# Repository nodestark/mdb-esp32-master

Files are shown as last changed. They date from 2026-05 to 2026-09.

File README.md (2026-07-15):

<div align="center">





# VMflow — MDB ESP32 Controller/Target Bridge

**A dual-port MDB bridge on the ESP32-S3, sitting between a vending machine's VMC and its peripherals.**
</div>

---

This project implements an **MDB bridge** between a vending machine's real VMC and its peripherals over the [Multi-Drop Bus](https://en.wikipedia.org/wiki/Multidrop_bus) protocol. The board exposes **two independent MDB ports**:

- **Controller port** — the board is the master: it drives the physical peripherals (coin changer `0x08` and bill validator `0x30`).
- **Target port** — the board is a slave: it emulates cashless (`0x10`), coin changer (`0x08`), and bill validator (`0x30`) toward the vending machine's real VMC.

The firmware bridges the two ports: coin/bill events detected on the controller port are relayed as MDB events on the target port (and enable/dispense/escrow commands the other way). Crucially, the target port **mirrors each physical peripheral's identity** to the VMC — its currency/country code, scale factor and decimal places — so the machine accepts them (a mismatched or unknown currency makes the VMC reject the device, e.g. `NOTE INCOMPAT`).

The cashless device (`0x10`) is **self-contained**: no physical cashless is bridged. Credit is granted out-of-band by the **VMflow payment engine** (BLE phone app) or the signed `credit` MQTT RPC, and each vend is approved locally against the session's available funds. Credit is bound to a single session — granted at Begin Session and destroyed at Session End/Reset — so no balance carries over or approves an out-of-session vend.

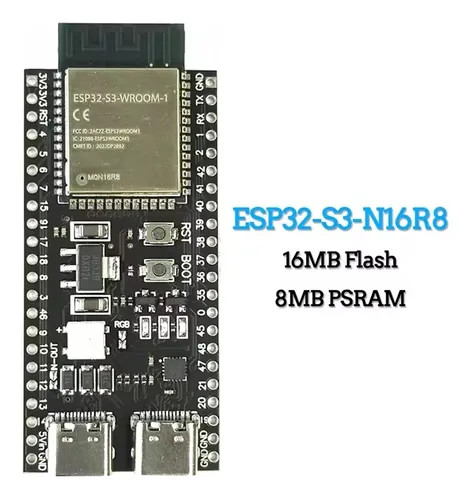
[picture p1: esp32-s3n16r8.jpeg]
ESP32-S3 N16R8


# Features
- **MDB controller↔target bridge**: bus poll loop, ACK/NAK/RET handling, 9-bit address/mode framing, on both an independent hardware-UART master port and a bit-banged slave port
- **Coin changer** (`0x08`) and **bill validator** (`0x30`) bridged as repeaters — the target port mirrors the real device's currency/country code, scale factor, decimal places, and tube/stacker counts, and forwards type-enable/dispense/escrow commands back to the physical device
- **Cashless** (`0x10`) **self-contained** on the target port — no physical cashless is bridged; credit is granted out-of-band and each vend is decided locally:
  - the **VMflow payment engine** — BLE (NimBLE) phone-app vend/session channel, HMAC-signed
  - the signed `credit` MQTT RPC command
  - credit is single-session (granted at Begin Session, destroyed at Session End/Reset); a vend is approved iff the item price fits the available funds
- **WiFi + MQTT** uplink (`mqtt.vmflow.xyz`) with signed remote-RPC commands (`info`, `safe`, `credit`, `oos`, `echo`, `restart`, `ota`) and telemetry (`vend_ok`, `vend_fail`, `sale`, `paxcounter`)
- **`info` RPC endpoint** reports firmware version, uptime and heap (plus a coin-vault snapshot)
- **`safe` RPC endpoint** reports cash currently in the machine: the **coin vault** (live tube count × per-coin credit — accurate) and the **bill vault** (value of bills stacked since boot; best-effort, since MDB never reports a bill's denomination once stacked), plus the raw bill stacker count
- **BLE passive-scan foot-traffic counter** ("paxcounter") — periodic scan classifying nearby phones by manufacturer ID/appearance, reported hourly
- **OTA** over HTTPS (`esp_https_ota`), triggered by the signed `ota` RPC command, pulling a release binary from this repo
- **WS2812 status LED** indicating provisioning/MQTT state
- Configurable via `idf.py menuconfig` → **VMflow** → MDB Cashless Device (currency/country code, scale factor, decimal places) — used as the fallback identity for any peripheral not (yet) online on the controller port
- Bare-metal **KiCad** hardware: MDB sockets + bridges, designed for low-cost production and customization
- Part of the open **VMflow** platform — pairs with the [📊 Web Dashboard](https://vmflow.xyz/dashboard) for telemetry, sales, inventory, and AI-powered diagnostics

# Hardware

The companion board (KiCad project [`kicad/`](kicad)) carries the ESP32-S3 module and the MDB interface bridge (TX/RX opto-isolation and the 9-bit UART path) plus the peripheral socket. Shared on PCBWay:

👉 **[MDB ESP32 Bridge Device — PCBWay](https://www.pcbway.com/project/shareproject/MDB_ESP32_Bridge_Device_ca013cf8.html)**

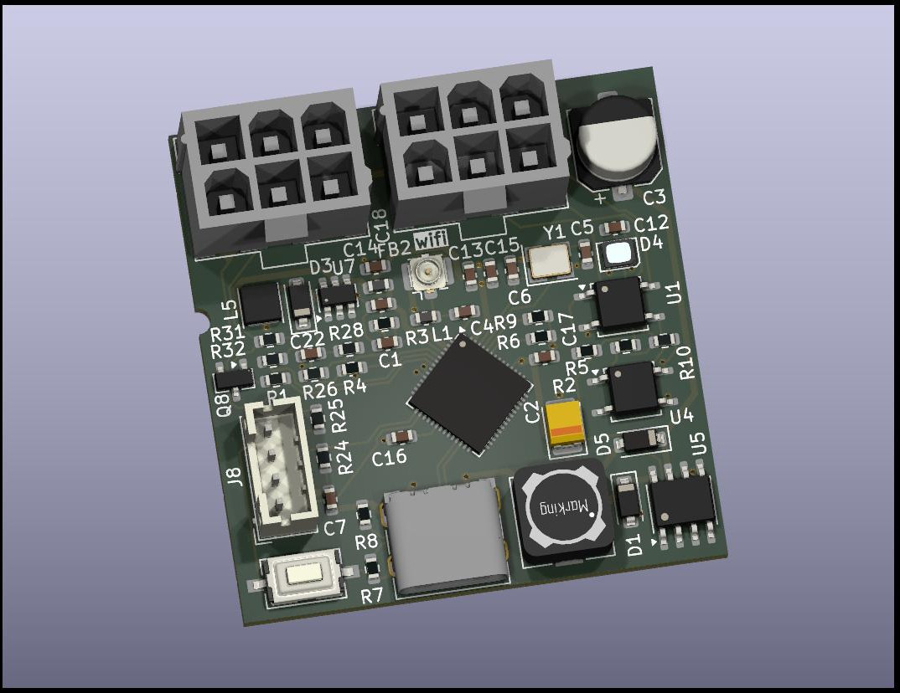
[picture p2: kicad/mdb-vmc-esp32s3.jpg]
MDB VMC ESP32-S3 PCB


PCBWay (https://www.pcbway.com/project/member/?bmbno=1B3B95CB-4E28-4D)

### MDB ports & pinout (default)

Two MDB ports — name reflects the board's role on each:

| Port | RX  | TX  | Board role | Connects to |
|---|-----|-----|---|---|
| **Controller**  | IO1 | IO2 | master (VMC) | peripherals: coin changer, bill validator |
| **Target** | IO4 | IO5 | slave (peripheral)  | the vending machine's VMC/master |

Both ports are driven at once by this firmware: peripherals plug into the **controller port**, the vending machine's real VMC plugs into the **target port**, and the firmware bridges the two.

Other pins:

| Signal | GPIO | Note |
|---|---|---|
| MDB state LED | 48 | WS2812 status LED |
| I2C SDA | 10 | reserved, not used by this firmware yet |
| I2C SCL | 11 | reserved, not used by this firmware yet |

MDB UART: 9600 baud, 9 data bits (8 data + 1 mode), even parity emulated for the 9th bit, 1 stop bit.

MDB PCB connection diagram

# Getting Started

Build with **ESP-IDF v5.x**:

```bash
# Clone the repository
git clone https://github.com/nodestark/mdb-esp32-master
cd mdb-esp32-master

idf.py menuconfig   # VMflow -> MDB Cashless Device: currency/country code, scale, decimal
idf.py build flash monitor
```

Wire the peripherals (coin changer, bill validator) to the **controller port**, and the vending machine's real VMC to the **target port**. Both sides start polling automatically — reset → setup → enable → poll. Provision WiFi/subdomain/passkey and use the cashless session from the VMflow phone app over BLE, or grant credit remotely via the signed `credit` MQTT RPC command.

# How to Contribute
- Contributions are welcome! Open issues, send pull requests, or propose new features
- Before submitting a pull request, make sure the code complies with the style and quality guidelines defined in the project
- Help improve documentation by adding usage examples, wiring notes, and peripheral compatibility reports

## License

This project is licensed under the MIT License - see the [LICENSE](LICENSE) file for details.

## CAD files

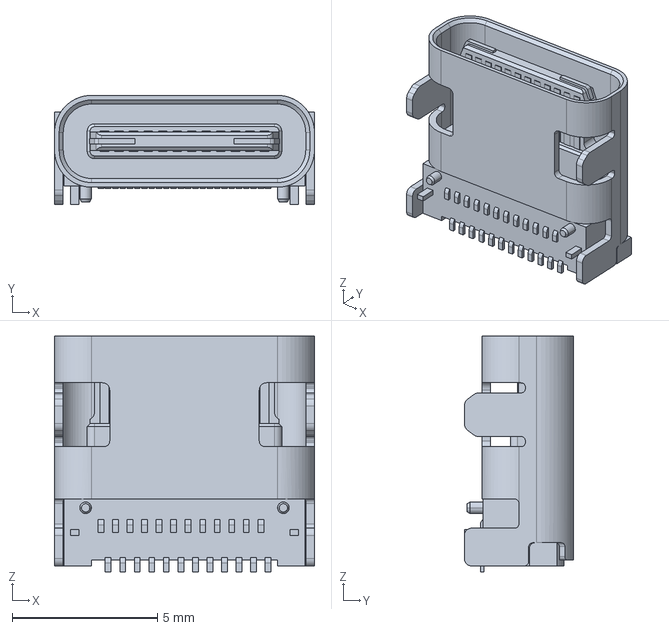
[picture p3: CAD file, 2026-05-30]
kicad/mdb-bridge-esp32s3/3d-models/USB-C_Receptacle_G-Switch-GT-USB-7010ASV.stp
8.94 x 3.76 x 8.10 mm

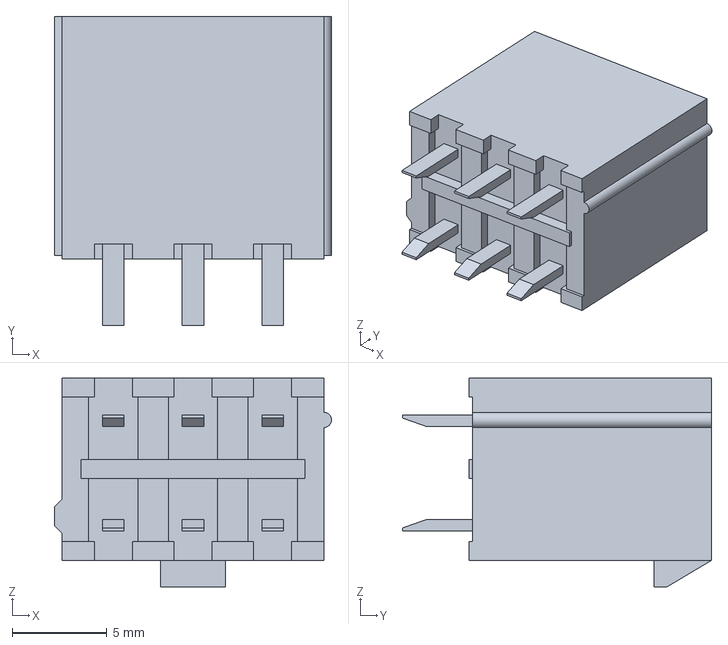
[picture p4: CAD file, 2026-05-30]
kicad/mdb-bridge-esp32s3/3d-models/Connector_Molex-MiniJr-39-28-1063_2x03.stp
14.6 x 16.3 x 11.0 mm

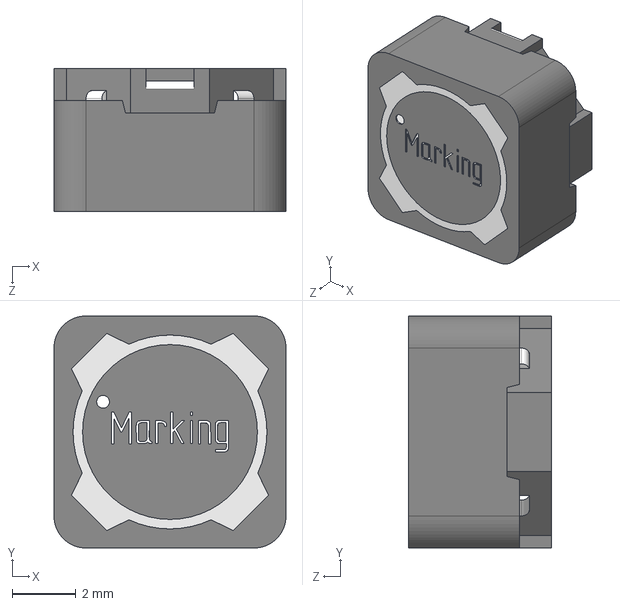
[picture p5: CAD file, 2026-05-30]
kicad/mdb-bridge-esp32s3/3d-models/Inductor_WE-7447789156_100uH.stp
7.30 x 7.30 x 4.50 mm

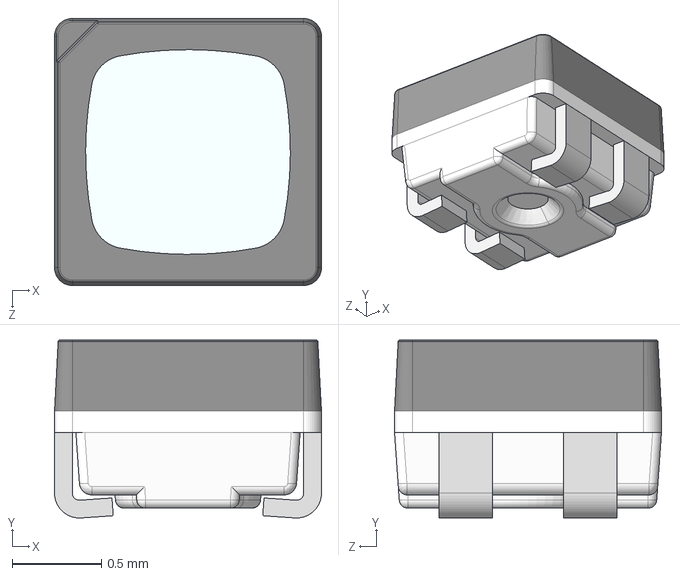
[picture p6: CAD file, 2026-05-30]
kicad/mdb-bridge-esp32s3/3d-models/LED_WS2812B-2020_XL-2121RGBC.stp
1.50 x 1 x 1.50 mm

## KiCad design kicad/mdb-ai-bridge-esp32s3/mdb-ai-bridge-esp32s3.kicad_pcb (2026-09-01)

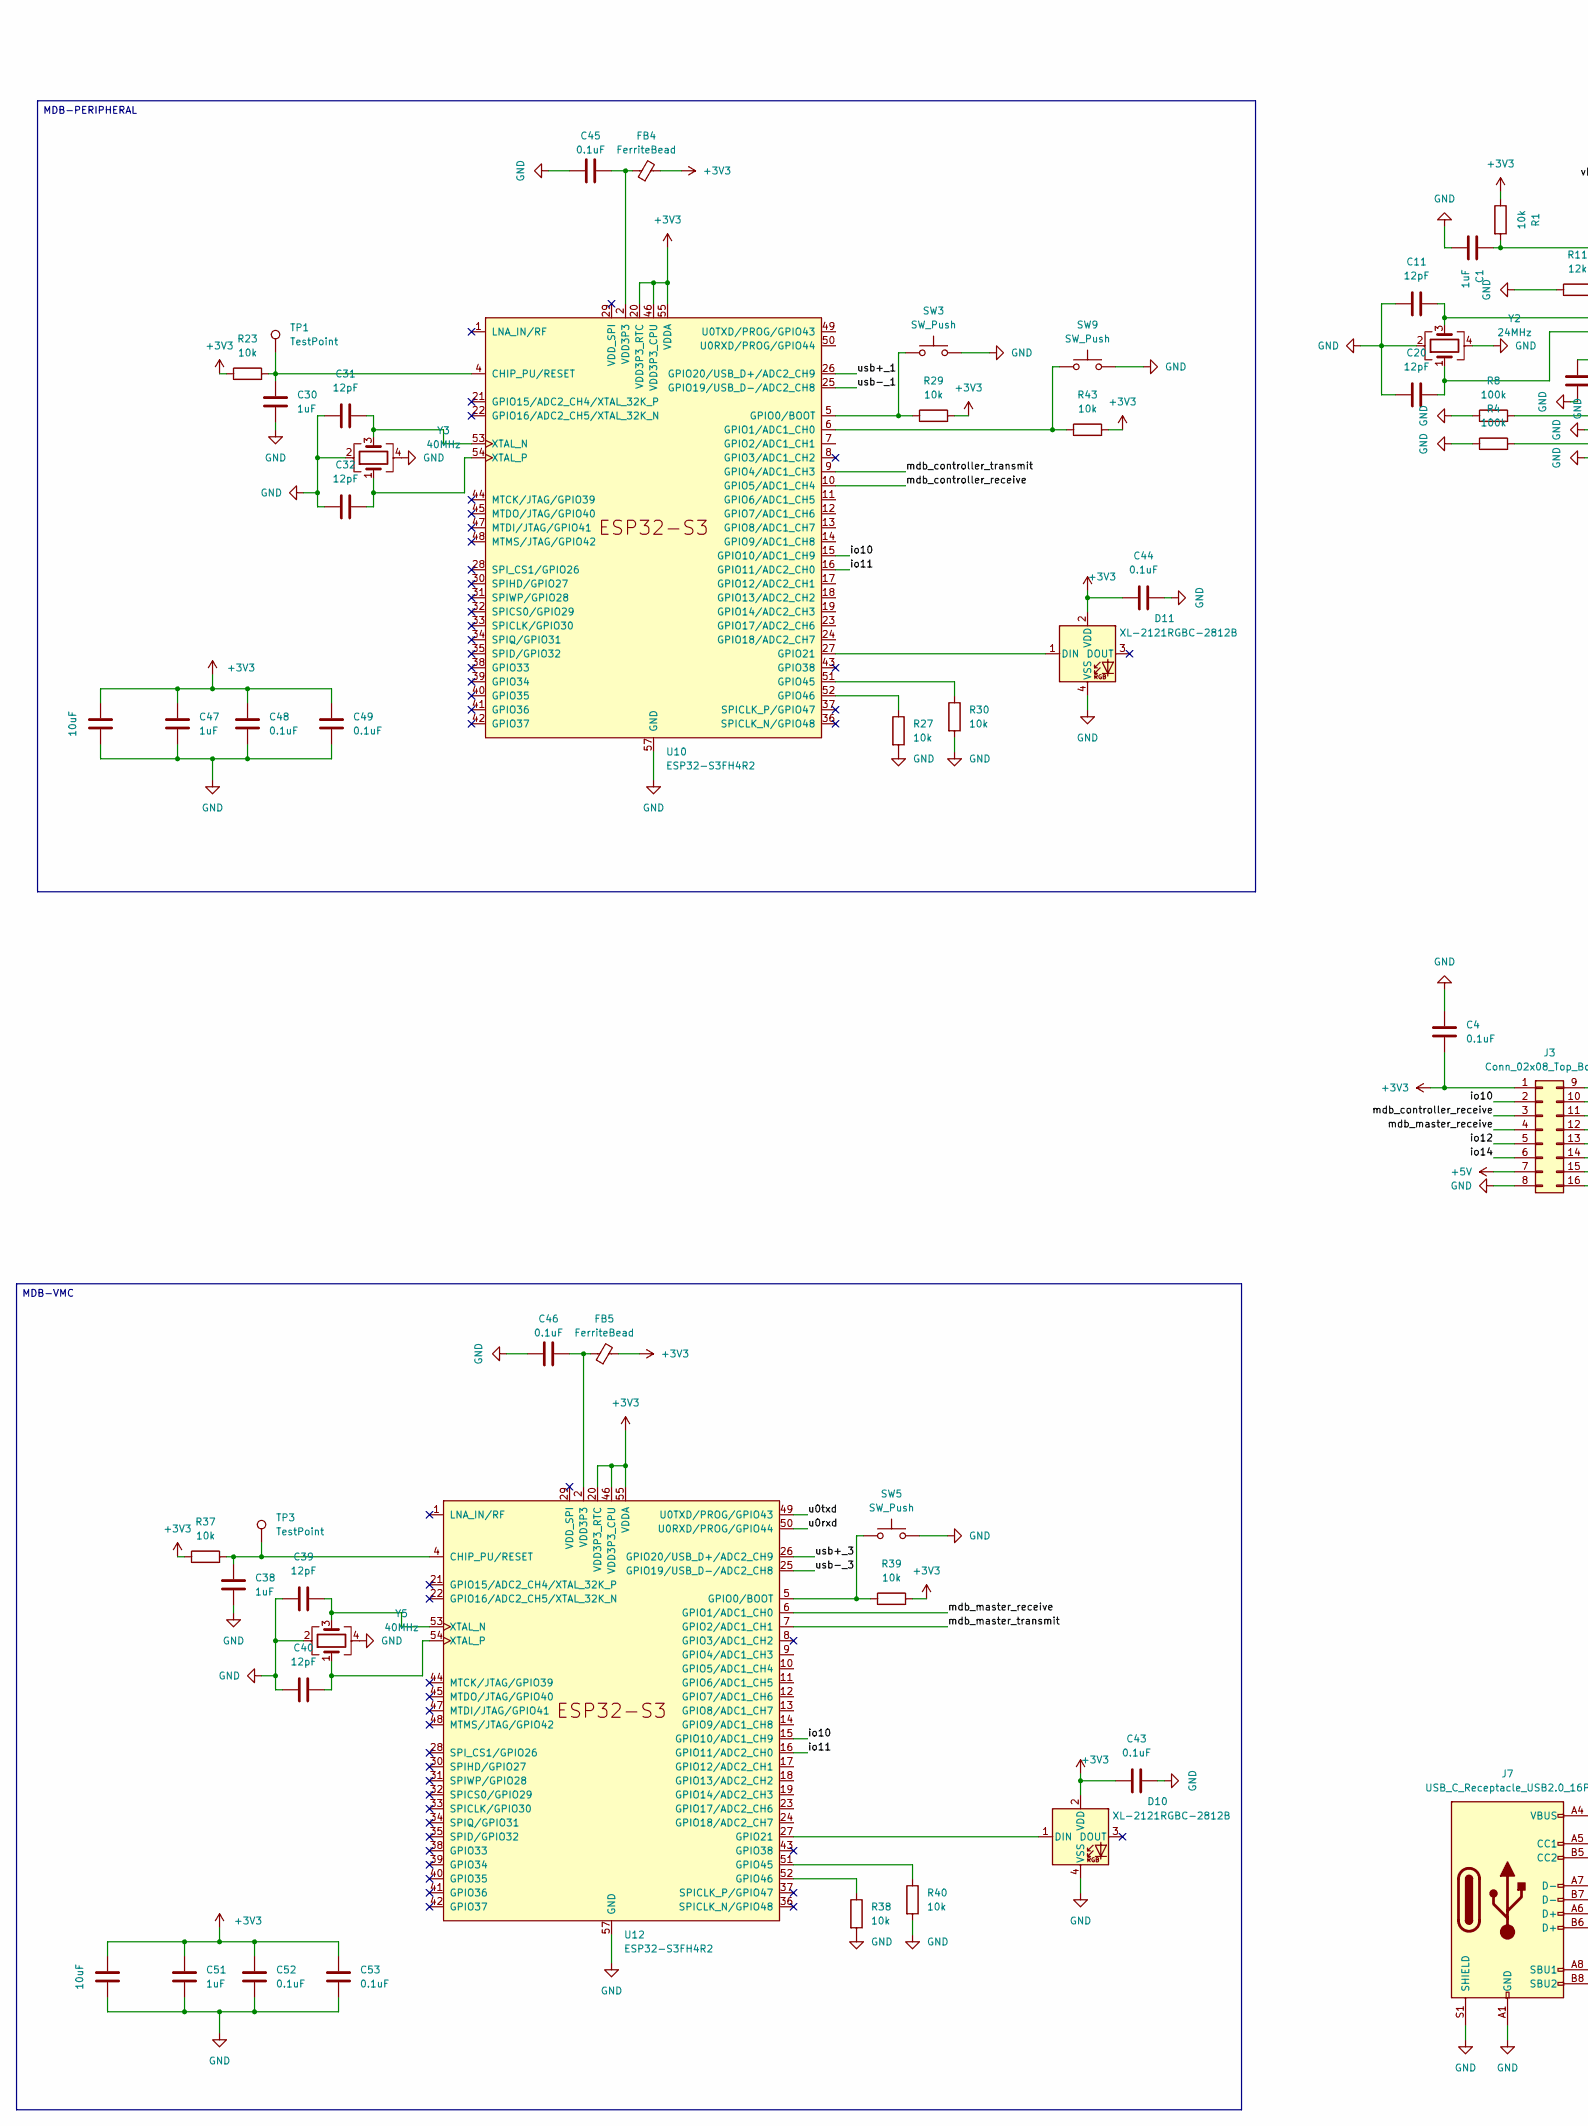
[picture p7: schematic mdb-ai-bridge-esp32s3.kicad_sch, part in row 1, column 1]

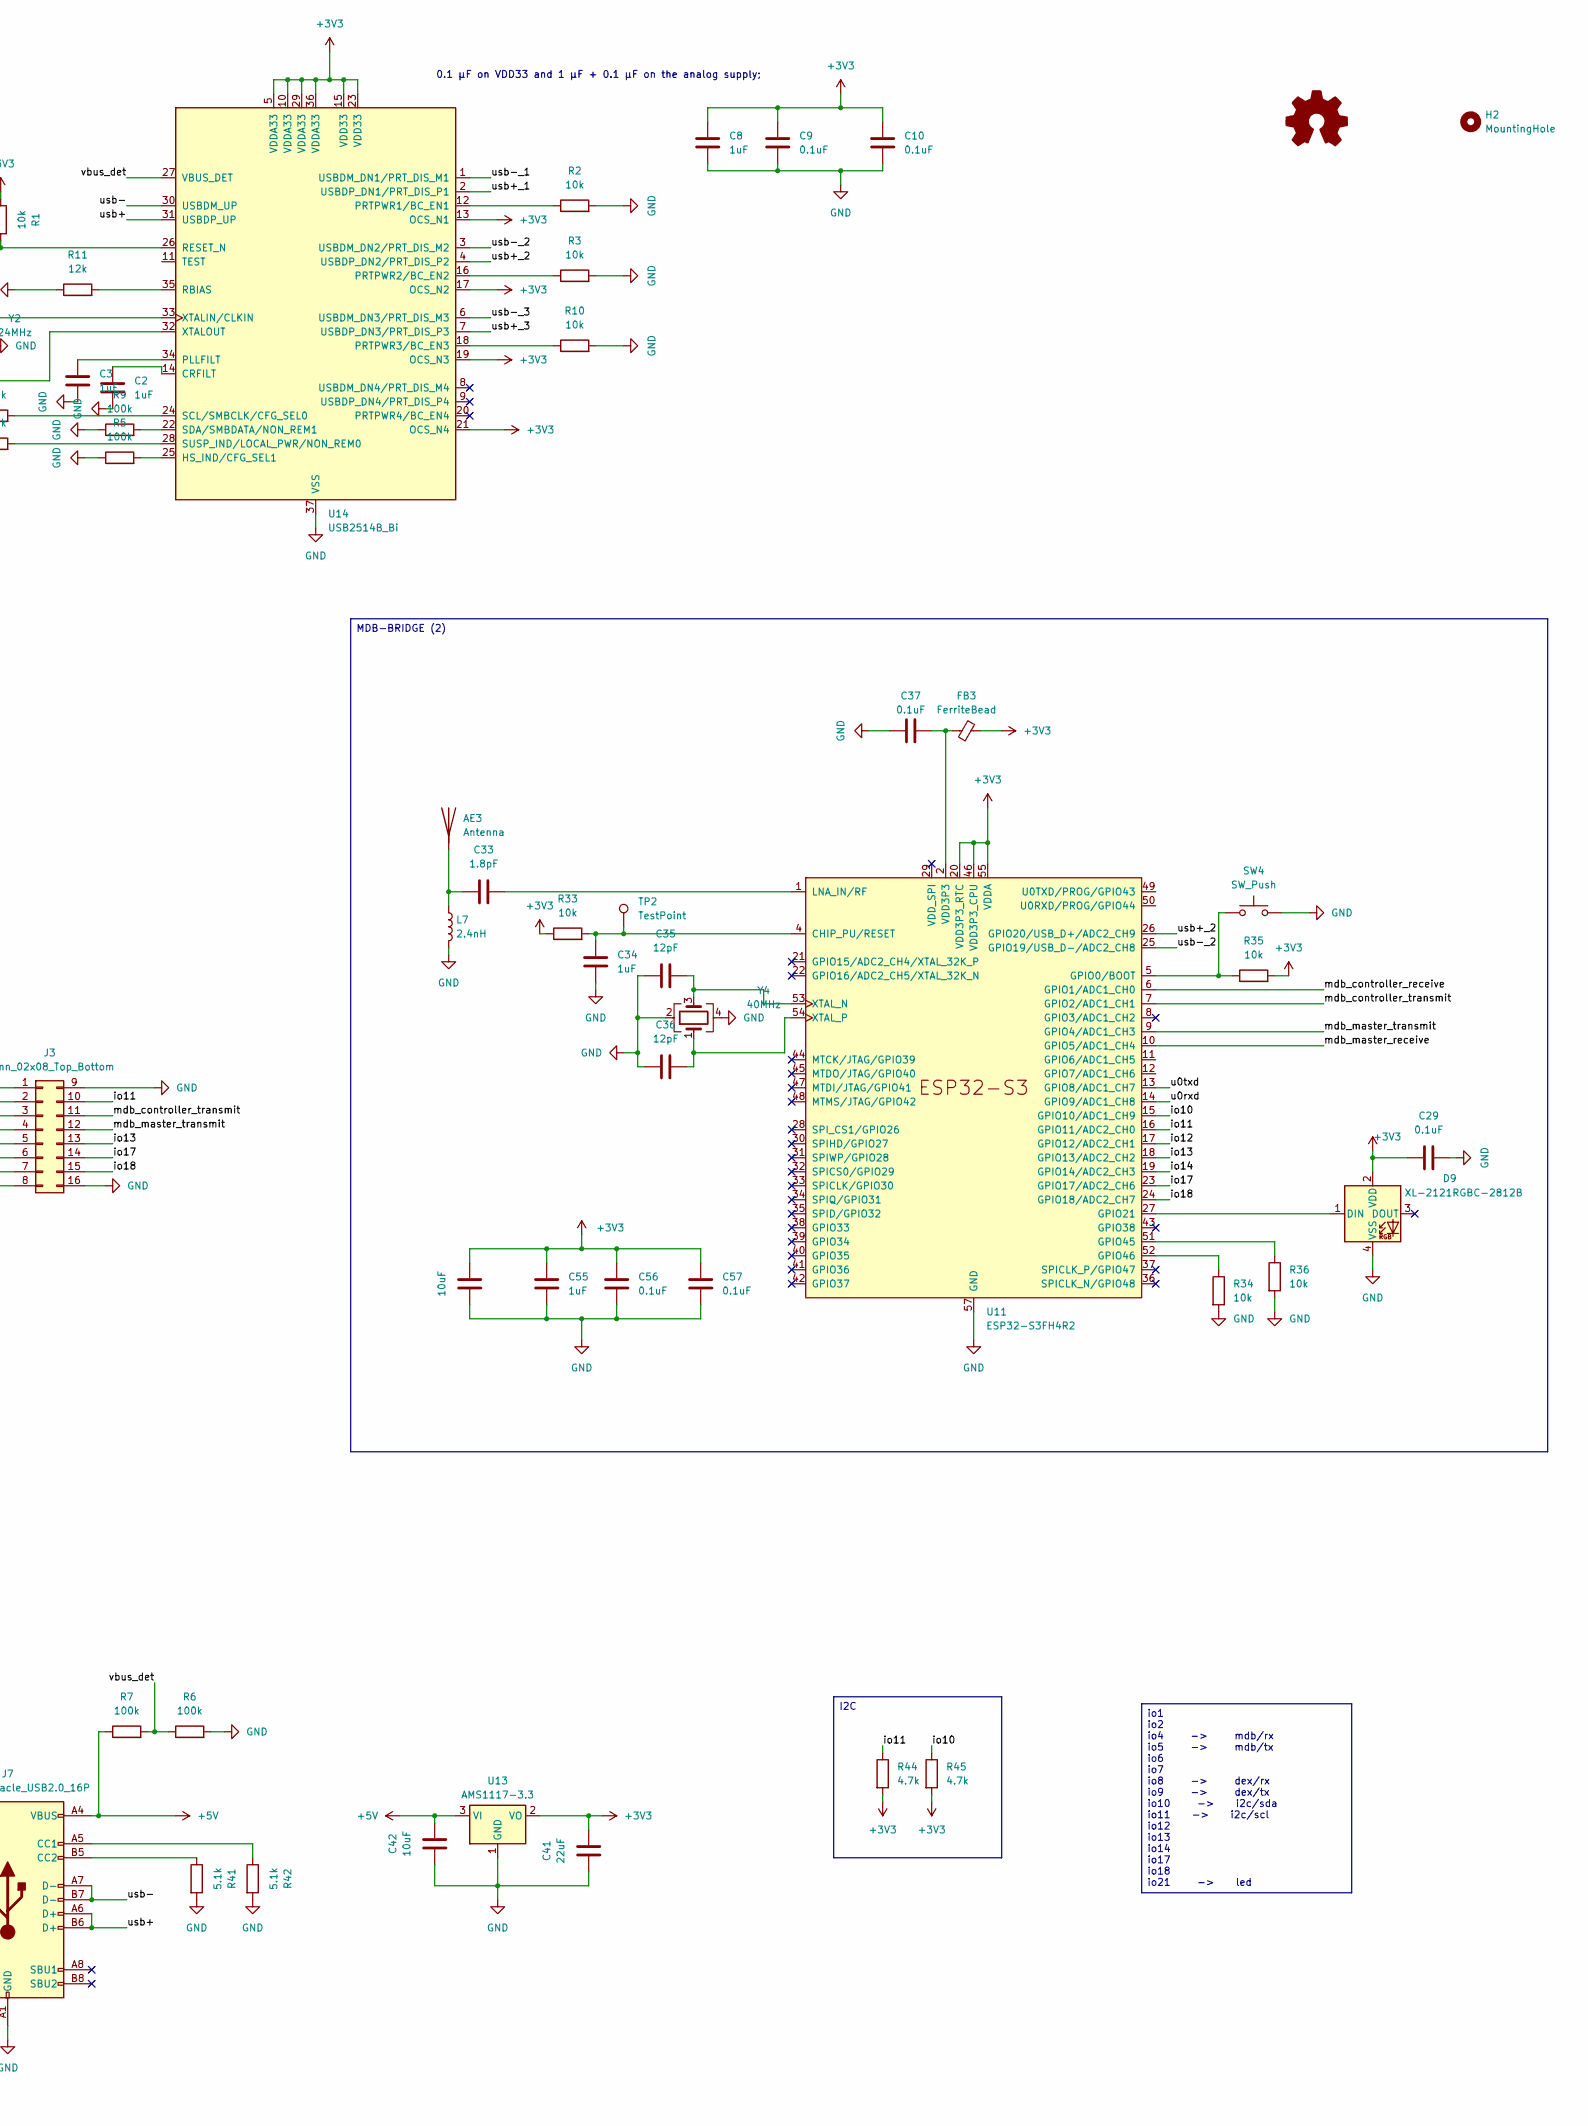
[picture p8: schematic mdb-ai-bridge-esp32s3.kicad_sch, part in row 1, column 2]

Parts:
AE3: Antenna; Texas_SWRA117D_2.4GHz_Right
C1, C2, C3, C8, C30, C34, C38, C47, C51, C55: 1uF; C_0603_1608Metric; LCSC# C6119849
C4, C9, C10, C29, C37, C43, C44, C45, C46, C48, C49, C52, C53, C56, C57: 0.1uF; C_0603_1608Metric; LCSC# C5137636
C11, C20, C31, C32, C35, C36, C39, C40: 12pF; C_0603_1608Metric; LCSC# C363546
C19, C42, C50, C54: 10uF; C_0603_1608Metric; LCSC# C6119864
C33: 1.8pF; C_0603_1608Metric; LCSC# C376773
C41: 22uF; C_0603_1608Metric; LCSC# C15500
D9, D10, D11: XL-2121RGBC-2812B; LED_WS2812B-2020_PLCC4_2.0x2.0mm; LCSC# C5349957
FB3, FB4, FB5: FerriteBead; L_0603_1608Metric; LCSC# C304319
H2: MountingHole; MountingHole_2.1mm
J3: Conn_02x08_Top_Bottom; PinHeader_2x08_P2.54mm_Vertical
J7: USB_C_Receptacle_USB2.0_16P; USB_C_Receptacle_G-Switch_GT-USB-7010ASV; LCSC# C2988369
L7: 2.4nH; L_0603_1608Metric; LCSC# C2042508
R1, R2, R3, R10, R23, R27, R29, R30, R33, R34, R35, R36, R37, R38, R39, R40, R43: 10k; R_0603_1608Metric; LCSC# C98220
R4, R5, R6, R7, R8, R9: 100k; R_0603_1608Metric; LCSC# C25803
R11: 12k; R_0603_1608Metric; LCSC# C22790
R41, R42: 5.1k; R_0603_1608Metric; LCSC# C394543
R44, R45: 4.7k; R_0603_1608Metric; LCSC# C23162
SW3, SW4, SW5, SW9: SW_Push; SW_Tactile_SPST_NO_Straight_CK_PTS636Sx25SMTRLFS; LCSC# C42435421
TP1, TP2, TP3: TestPoint; TestPoint_Pad_D1.5mm
U10, U11, U12: ESP32-S3FH4R2; QFN-56-1EP_7x7mm_P0.4mm_EP4x4mm; LCSC# C3013940
U13: AMS1117-3.3; SOT-223-3_TabPin2; LCSC# C6186
U14: USB2514B_Bi; QFN-36-1EP_6x6mm_P0.5mm_EP3.7x3.7mm; LCSC# C510949
Y2: 24MHz; Crystal_SMD_3225-4Pin_3.2x2.5mm; LCSC# C19725352
Y3, Y4, Y5: 40MHz; Crystal_SMD_3225-4Pin_3.2x2.5mm; LCSC# C7294599

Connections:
+3V3: C4.1, C8.2, C9.1, C10.1, C19.2, C29.2, C41.2, C43.2, C44.2, C47.2, C48.1, C49.1, C50.2, C51.2, C52.1, C53.1, C54.2, C55.2, C56.1, C57.1, D9.2 (VDD), D10.2 (VDD), D11.2 (VDD), FB3.2, FB4.2, FB5.2, J3.1, R1.1, R23.1, R29.2, R33.1, R35.2, R37.1, R39.2, R43.2, R44.2, R45.2, U10.20 (VDD3P3_RTC), U10.46 (VDD3P3_CPU), U10.55 (VDDA), U10.56 (VDDA), U11.20 (VDD3P3_RTC), U11.46 (VDD3P3_CPU), U11.55 (VDDA), U11.56 (VDDA), U12.20 (VDD3P3_RTC), U12.46 (VDD3P3_CPU), U12.55 (VDDA), U12.56 (VDDA), U13.2 (VO), U14.5 (VDDA33), U14.10 (VDDA33), U14.13 (OCS_N1), U14.15 (VDD33), U14.17 (OCS_N2), U14.19 (OCS_N3), U14.21 (OCS_N4), U14.23 (VDD33), U14.29 (VDDA33), U14.36 (VDDA33)
+5V: C42.2, J3.7, J7.A4 (VBUS), J7.A9 (VBUS), J7.B4 (VBUS), J7.B9 (VBUS), R7.1, U13.3 (VI)
/io10: J3.2, R45.1, U10.15 (GPIO10/ADC1_CH9), U11.15 (GPIO10/ADC1_CH9), U12.15 (GPIO10/ADC1_CH9)
/io11: J3.10, R44.1, U10.16 (GPIO11/ADC2_CH0), U11.16 (GPIO11/ADC2_CH0), U12.16 (GPIO11/ADC2_CH0)
/io12: J3.5, U11.17 (GPIO12/ADC2_CH1)
/io13: J3.13, U11.18 (GPIO13/ADC2_CH2)
/io14: J3.6, U11.19 (GPIO14/ADC2_CH3)
/io17: J3.14, U11.23 (GPIO17/ADC2_CH6)
/io18: J3.15, U11.24 (GPIO18/ADC2_CH7)
/mdb_controller_receive: J3.3, U10.10 (GPIO5/ADC1_CH4), U11.6 (GPIO1/ADC1_CH0)
/mdb_controller_transmit: J3.11, U10.9 (GPIO4/ADC1_CH3), U11.7 (GPIO2/ADC1_CH1)
/mdb_master_receive: J3.4, U11.10 (GPIO5/ADC1_CH4), U12.6 (GPIO1/ADC1_CH0)
/mdb_master_transmit: J3.12, U11.9 (GPIO4/ADC1_CH3), U12.7 (GPIO2/ADC1_CH1)
/u0rxd: U11.14 (GPIO9/ADC1_CH8), U12.50 (U0RXD/PROG/GPIO44)
/u0txd: U11.13 (GPIO8/ADC1_CH7), U12.49 (U0TXD/PROG/GPIO43)
/usb+: J7.A6 (D+), J7.B6 (D+), U14.31 (USBDP_UP)
/usb+_1: U10.26 (GPIO20/USB_D+/ADC2_CH9), U14.2 (USBDP_DN1/PRT_DIS_P1)
/usb+_2: U11.26 (GPIO20/USB_D+/ADC2_CH9), U14.4 (USBDP_DN2/PRT_DIS_P2)
/usb+_3: U12.26 (GPIO20/USB_D+/ADC2_CH9), U14.7 (USBDP_DN3/PRT_DIS_P3)
/usb-: J7.A7 (D-), J7.B7 (D-), U14.30 (USBDM_UP)
/usb-_1: U10.25 (GPIO19/USB_D-/ADC2_CH8), U14.1 (USBDM_DN1/PRT_DIS_M1)
/usb-_2: U11.25 (GPIO19/USB_D-/ADC2_CH8), U14.3 (USBDM_DN2/PRT_DIS_M2)
/usb-_3: U12.25 (GPIO19/USB_D-/ADC2_CH8), U14.6 (USBDM_DN3/PRT_DIS_M3)
/vbus_det: R6.1, R7.2, U14.27 (VBUS_DET)
GND: C1.2, C2.1, C3.1, C4.2, C8.1, C9.2, C10.2, C11.1, C19.1, C20.1, C29.1, C30.2, C31.1, C32.1, C34.2, C35.1, C36.1, C37.1, C38.2, C39.1, C40.1, C41.1, C42.1, C43.1, C44.1, C45.1, C46.1, C47.1, C48.2, C49.2, C50.1, C51.1, C52.2, C53.2, C54.1, C55.1, C56.2, C57.2, D9.4 (VSS), D10.4 (VSS), D11.4 (VSS), J3.8, J3.9, J3.16, J7.A1 (GND), J7.A12 (GND), J7.B1 (GND), J7.B12 (GND), J7.S1 (SHIELD), L7.2, R2.2, R3.2, R4.1, R5.1, R6.2, R8.1, R9.1, R10.2, R11.1, R27.2, R30.2, R34.2, R36.2, R38.2, R40.2, R41.2, R42.2, SW3.2, SW4.2, SW5.2, SW9.2, U10.57 (GND), U11.57 (GND), U12.57 (GND), U13.1 (GND), U14.37 (VSS), Y2.2, Y2.4, Y3.2, Y3.4, Y4.2, Y4.4, Y5.2, Y5.4
unnamed: AE3.1 (A), C33.1, L7.1
unnamed: D9.1 (DIN), U11.27 (GPIO21)
unnamed: D10.1 (DIN), U12.27 (GPIO21)
unnamed: D11.1 (DIN), U10.27 (GPIO21)
unnamed: J7.A5 (CC1), R42.1
unnamed: J7.B5 (CC2), R41.1
unnamed: C30.1, R23.2, TP1.1, U10.4 (CHIP_PU/RESET)
unnamed: R29.1, SW3.1, U10.5 (GPIO0/BOOT)
unnamed: R43.1, SW9.1, U10.6 (GPIO1/ADC1_CH0)
unnamed: R30.1, U10.51 (GPIO45)
unnamed: R27.1, U10.52 (GPIO46)
unnamed: C31.2, U10.53 (XTAL_N), Y3.3
unnamed: C32.2, U10.54 (XTAL_P), Y3.1
unnamed: C34.1, R33.2, TP2.1, U11.4 (CHIP_PU/RESET)
unnamed: R35.1, SW4.1, U11.5 (GPIO0/BOOT)
unnamed: R36.1, U11.51 (GPIO45)
unnamed: R34.1, U11.52 (GPIO46)
unnamed: C33.2, U11.1 (LNA_IN/RF)
unnamed: C35.2, U11.53 (XTAL_N), Y4.3
unnamed: C36.2, U11.54 (XTAL_P), Y4.1
unnamed: C38.1, R37.2, TP3.1, U12.4 (CHIP_PU/RESET)
unnamed: R39.1, SW5.1, U12.5 (GPIO0/BOOT)
unnamed: R40.1, U12.51 (GPIO45)
unnamed: R38.1, U12.52 (GPIO46)
unnamed: C39.2, U12.53 (XTAL_N), Y5.3
unnamed: C40.2, U12.54 (XTAL_P), Y5.1
unnamed: C2.2, U14.14 (CRFILT)
unnamed: R5.2, U14.25 (HS_IND/CFG_SEL1)
unnamed: C3.2, U14.34 (PLLFILT)
unnamed: R2.1, U14.12 (PRTPWR1/BC_EN1)
unnamed: R3.1, U14.16 (PRTPWR2/BC_EN2)
unnamed: R10.1, U14.18 (PRTPWR3/BC_EN3)
unnamed: R11.2, U14.35 (RBIAS)
unnamed: C1.1, R1.2, U14.26 (RESET_N)
unnamed: R8.2, U14.24 (SCL/SMBCLK/CFG_SEL0)
unnamed: R9.2, U14.22 (SDA/SMBDATA/NON_REM1)
unnamed: R4.2, U14.28 (SUSP_IND/LOCAL_PWR/NON_REM0)
unnamed: C11.2, U14.33 (XTALIN/CLKIN), Y2.3
unnamed: C20.2, U14.32 (XTALOUT), Y2.1

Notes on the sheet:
0.1 µF on VDD33 and 1 µF + 0.1 µF on the analog supply;
MDB-PERIPHERAL
MDB-BRIDGE (2)
MDB-VMC
io1 io2 io4 -> mdb/rx io5 -> mdb/tx io6 io7 io8 -> dex/rx io9 -> dex/tx io10 -> i2c/sda io11 -> i2c/scl io12 io13 io14 io17 io18 io21 -> led
I2C

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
Board: 2 copper layers, 94 parts (0 on the bottom side), 65 nets, no tracks yet.

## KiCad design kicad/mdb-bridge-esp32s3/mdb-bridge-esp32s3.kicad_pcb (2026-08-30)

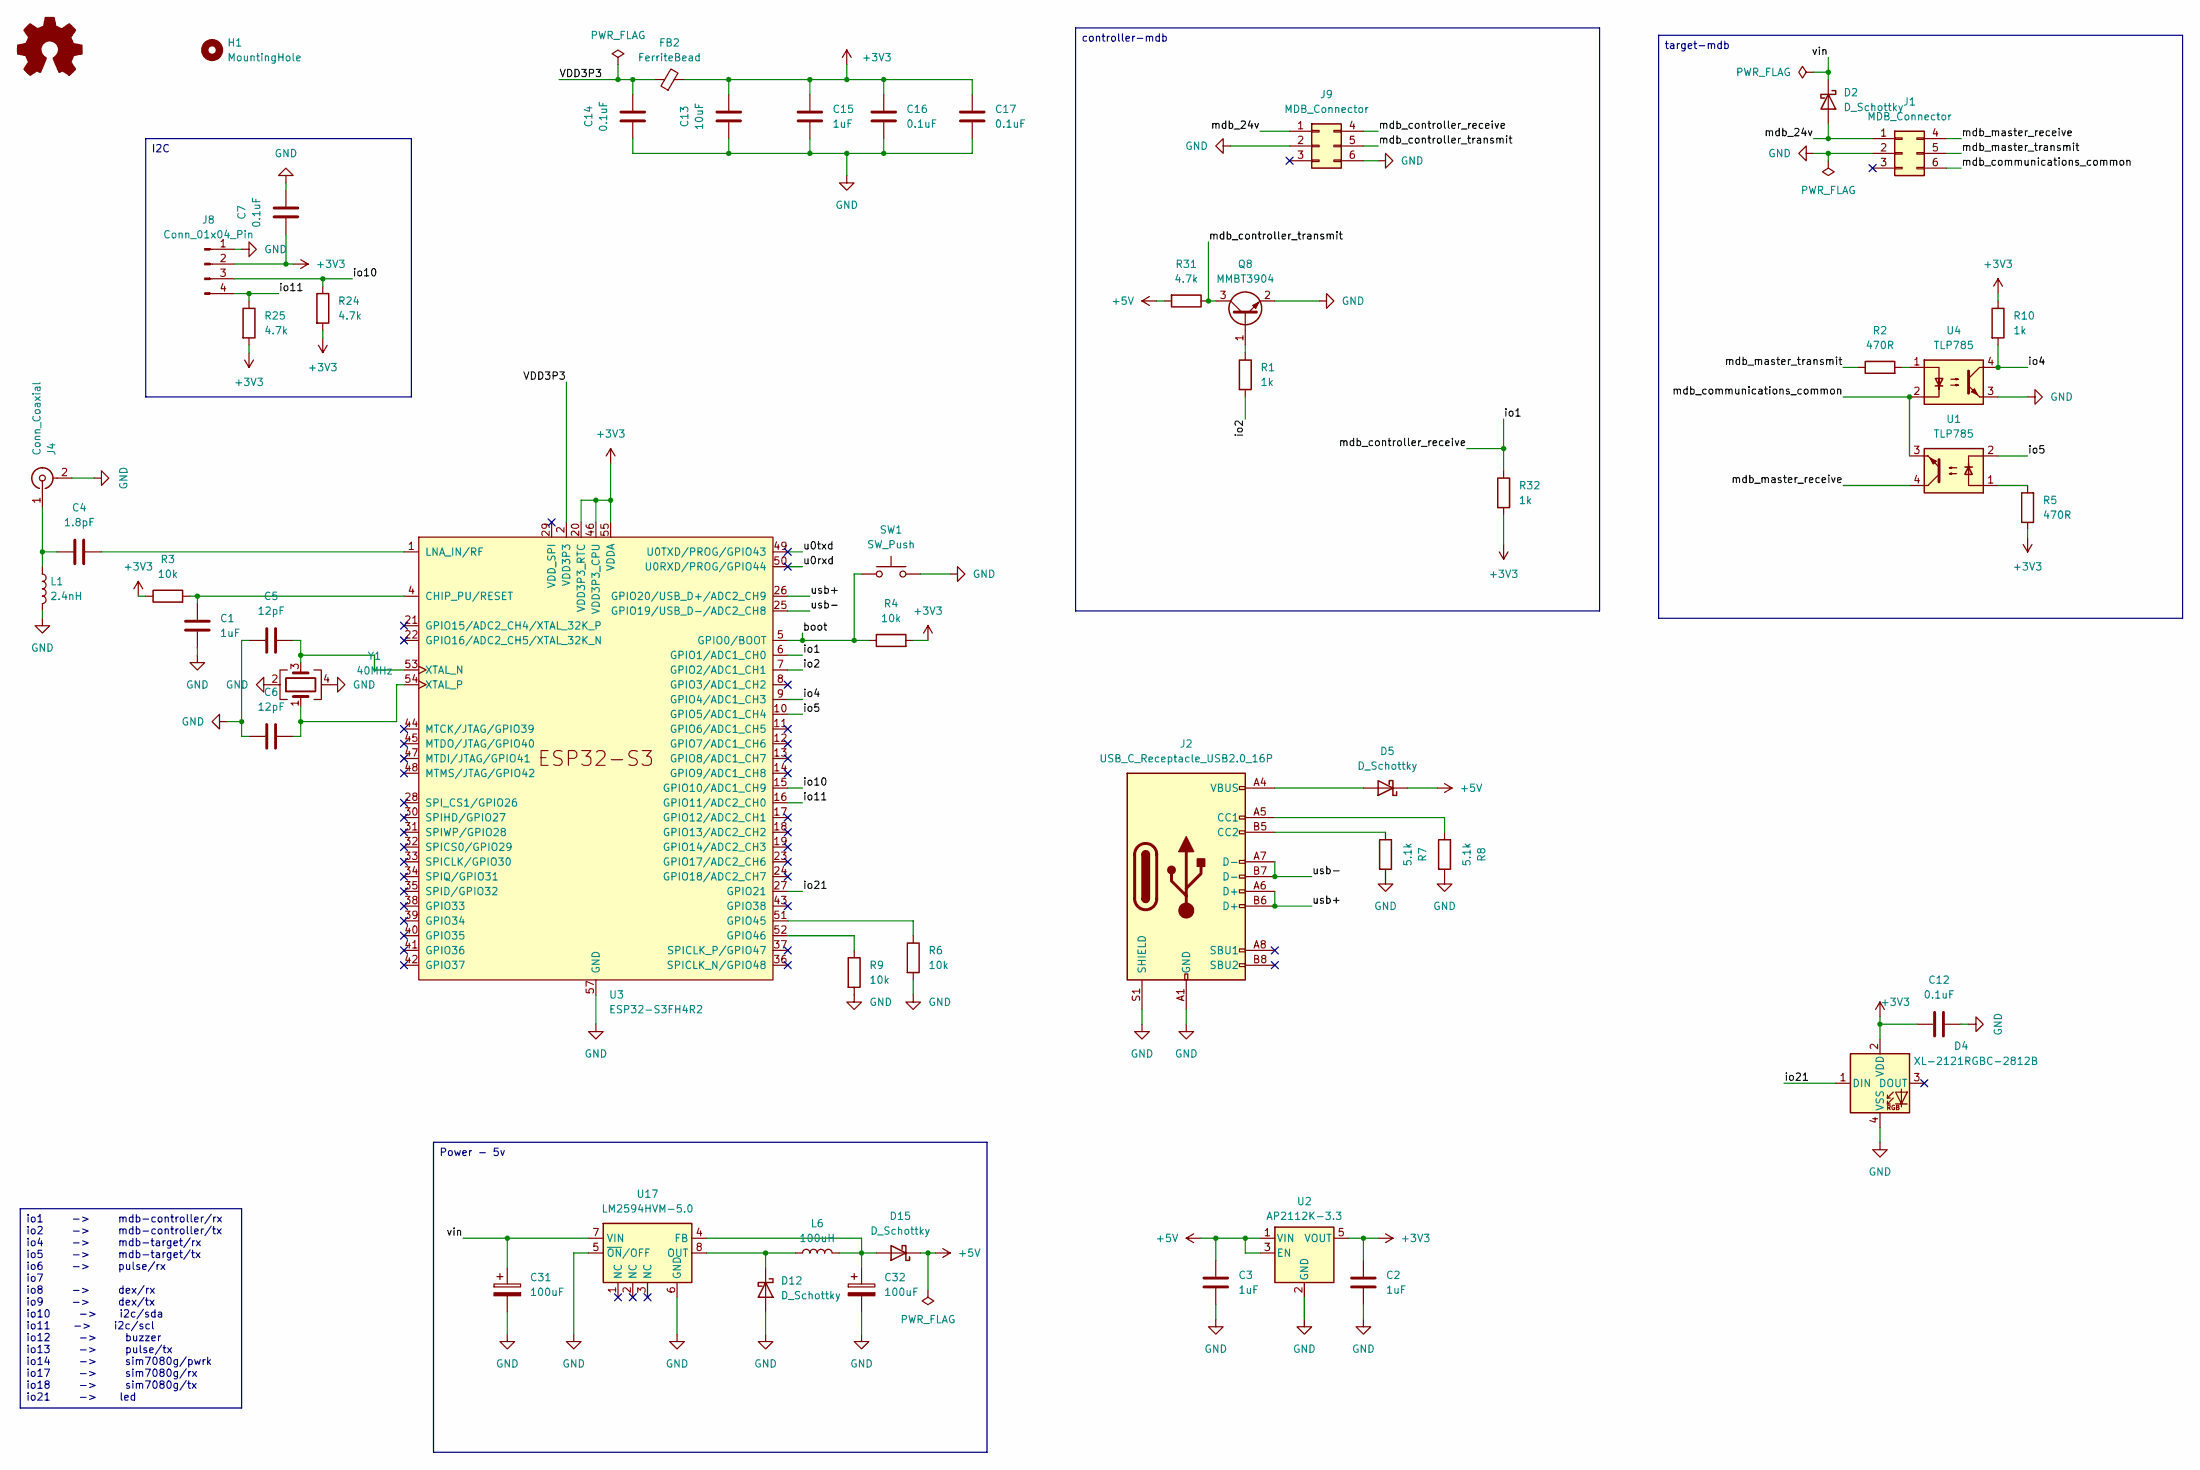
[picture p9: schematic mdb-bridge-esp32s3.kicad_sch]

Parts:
C1, C2, C3, C15: 1uF; C_0603_1608Metric; LCSC# C696901
C4: 1.8pF; C_0603_1608Metric; LCSC# C376773
C5, C6: 12pF; C_0603_1608Metric; LCSC# C363546
C7, C12, C14, C16, C17: 0.1uF; C_0603_1608Metric; LCSC# C5137636
C13: 10uF; C_0603_1608Metric; LCSC# C6119864
C31: 100uF; CP_Elec_6.3x5.8; LCSC# C128464
C32: 100uF; CP_EIA-3528-21_Kemet-B; LCSC# C90975
D2, D5, D12, D15: D_Schottky; D_SOD-123; LCSC# C18195164
D4: XL-2121RGBC-2812B; LED_WS2812B-2020_PLCC4_2.0x2.0mm; LCSC# C5349957
FB2: FerriteBead; L_0603_1608Metric; LCSC# C304319
H1: MountingHole; MountingHole_2.1mm
J1, J9: MDB_Connector; Molex_Mini-Fit_Jr_5566-06A_2x03_P4.20mm_Vertical; LCSC# C22365701
J2: USB_C_Receptacle_USB2.0_16P; USB_C_Receptacle_G-Switch_GT-USB-7010ASV; LCSC# C2988369
J4: Conn_Coaxial; U.FL_Hirose_U.FL-R-SMT-1_Vertical; LCSC# C88374
J8: Conn_01x04_Pin; JST_PH_B4B-PH-K_1x04_P2.00mm_Vertical; LCSC# C131334
L1: 2.4nH; L_0603_1608Metric; LCSC# C2042508
L6: 100uH; L_7.3x7.3_H3.5; LCSC# C182195
Q8: MMBT3904; SOT-23; LCSC# C916374
R1, R10, R32: 1k; R_0603_1608Metric; LCSC# C2907113
R2, R5: 470R; R_0603_1608Metric; LCSC# C114669
R3, R4, R6, R9: 10k; R_0603_1608Metric; LCSC# C98220
R7, R8: 5.1k; R_0603_1608Metric; LCSC# C394543
R24, R25, R31: 4.7k; R_0603_1608Metric; LCSC# C23162
SW1: SW_Push; SW_Tactile_SPST_NO_Straight_CK_PTS636Sx25SMTRLFS; LCSC# C42435421
U1, U4: TLP785; SOP-4_3.8x4.1mm_P2.54mm; LCSC# C45445
U2: AP2112K-3.3; SOT-23-5; LCSC# C51118
U3: ESP32-S3FH4R2; QFN-56-1EP_7x7mm_P0.4mm_EP4x4mm; LCSC# C3013940
U17: LM2594HVM-5.0; SOIC-8_3.9x4.9mm_P1.27mm; LCSC# C2904794
Y1: 40MHz; Crystal_SMD_3225-4Pin_3.2x2.5mm; LCSC# C7294599

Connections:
+3V3: C2.2, C7.1, C12.2, C13.2, C15.2, C16.1, C17.1, D4.2 (VDD), FB2.2, J8.2, R3.1, R4.2, R5.1, R10.1, R24.2, R25.2, R32.2, U2.5 (VOUT), U3.20 (VDD3P3_RTC), U3.46 (VDD3P3_CPU), U3.55 (VDDA), U3.56 (VDDA)
+5V: C3.2, D5.1 (K), D15.1 (K), R31.2, U2.1 (VIN), U2.3 (EN)
/boot: R4.1, SW1.1, U3.5 (GPIO0/BOOT)
/io1: J9.4, R32.1, U3.6 (GPIO1/ADC1_CH0)
/io2: R1.2, U3.7 (GPIO2/ADC1_CH1)
/io4: R10.2, U3.9 (GPIO4/ADC1_CH3), U4.4
/io5: U1.2, U3.10 (GPIO5/ADC1_CH4)
/io10: J8.3, R24.1, U3.15 (GPIO10/ADC1_CH9)
/io11: J8.4, R25.1, U3.16 (GPIO11/ADC2_CH0)
/io21: D4.1 (DIN), U3.27 (GPIO21)
/mdb_24v: D2.2 (A), J1.1, J9.1
/mdb_communications_common: J1.6, U1.3, U4.2
/mdb_controller_transmit: J9.5, Q8.3 (C), R31.1
/mdb_master_receive: J1.4, U1.4
/mdb_master_transmit: J1.5, R2.1
/u0rxd: U3.50 (U0RXD/PROG/GPIO44)
/u0txd: U3.49 (U0TXD/PROG/GPIO43)
/usb+: J2.A6 (D+), J2.B6 (D+), U3.26 (GPIO20/USB_D+/ADC2_CH9)
/usb-: J2.A7 (D-), J2.B7 (D-), U3.25 (GPIO19/USB_D-/ADC2_CH8)
/vin: C31.1, D2.1 (K), U17.7 (VIN)
GND: C1.2, C2.1, C3.1, C5.1, C6.1, C7.2, C12.1, C13.1, C14.1, C15.1, C16.2, C17.2, C31.2, C32.2, D4.4 (VSS), D12.2 (A), J1.2, J2.A1 (GND), J2.A12 (GND), J2.B1 (GND), J2.B12 (GND), J2.S1 (SHIELD), J4.2 (Ext), J8.1, J9.2, J9.6, L1.2, Q8.2 (E), R6.2, R7.2, R8.2, R9.2, SW1.2, U2.2 (GND), U3.57 (GND), U4.3, U17.5 (~ON/OFF), U17.6 (GND), Y1.2, Y1.4
unnamed: D5.2 (A), J2.A4 (VBUS), J2.A9 (VBUS), J2.B4 (VBUS), J2.B9 (VBUS)
unnamed: D12.1 (K), L6.1, U17.8 (OUT)
unnamed: C32.1, D15.2 (A), L6.2, U17.4 (FB)
unnamed: J2.A5 (CC1), R8.1
unnamed: J2.B5 (CC2), R7.1
unnamed: C4.1, J4.1 (In), L1.1
unnamed: Q8.1 (B), R1.1
unnamed: R2.2, U4.1
unnamed: R5.2, U1.1
unnamed: C1.1, R3.2, U3.4 (CHIP_PU/RESET)
unnamed: R6.1, U3.51 (GPIO45)
unnamed: R9.1, U3.52 (GPIO46)
unnamed: C4.2, U3.1 (LNA_IN/RF)
unnamed: C5.2, U3.53 (XTAL_N), Y1.3
unnamed: C6.2, U3.54 (XTAL_P), Y1.1
VDD3P3: C14.2, FB2.1, U3.2 (VDD3P3), U3.3 (VDD3P3)

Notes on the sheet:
io1 -> mdb-controller/rx io2 -> mdb-controller/tx io4 -> mdb-target/rx io5 -> mdb-target/tx io6 -> pulse/rx io7 io8 -> dex/rx io9 -> dex/tx io10 -> i2c/sda io11 -> i2c/scl io12 -> buzzer io13 -> pulse/tx io14 -> sim7080g/pwrk io17 -> sim7080g/rx io18 -> sim7080g/tx io21 -> led
controller-mdb
Power - 5v
I2C
target-mdb

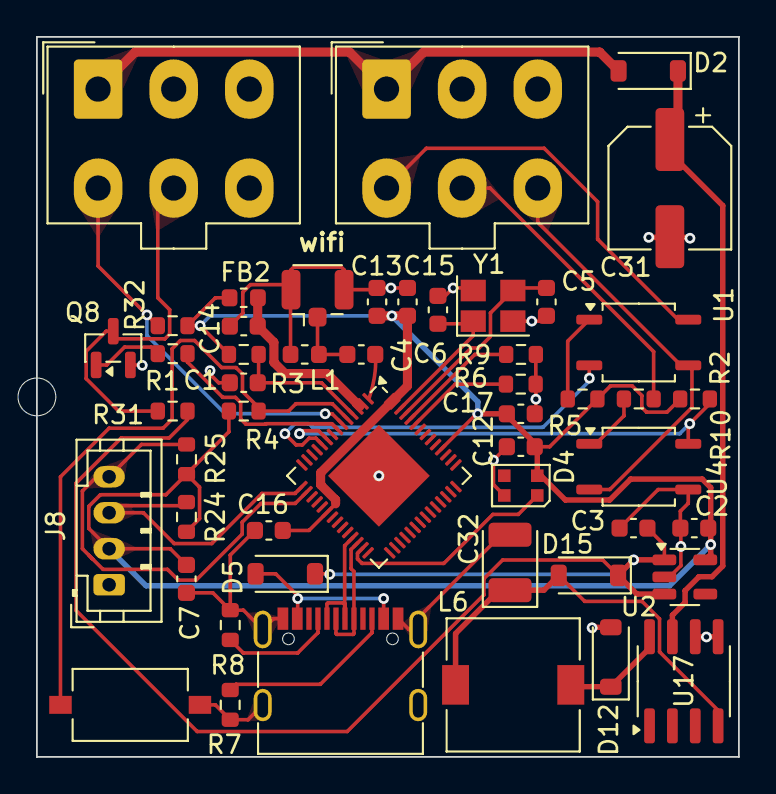
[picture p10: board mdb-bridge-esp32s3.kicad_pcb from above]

Board: 2 copper layers, 39.0 x 40.0 mm, 51 parts (0 on the bottom side), 35 nets.

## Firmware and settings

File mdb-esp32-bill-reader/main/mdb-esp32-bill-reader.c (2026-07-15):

/*
 * VMflow.xyz
 *
 * mdb-esp32-bill-reader.c - MDB Bill Validator peripheral (ESP32-S3)
 *
 * Emulates an MDB Level 1 bill validator (address 0x30). The BOOT button
 * on GPIO0 injects a $1 bill (type 0) event for bench testing.
 *
 * MDB lines are bit-banged at 9600 baud, 9 data bits (the 9th bit is the
 * MODE bit). RX is sampled inside a falling-edge ISR; TX is shifted out by
 * busy-wait. Same low-level scheme as the cashless peripheral.
 */

#include <stdio.h>
#include <string.h>
#include <freertos/FreeRTOS.h>
#include <freertos/task.h>
#include <freertos/queue.h>
#include <esp_log.h>
#include <esp_timer.h>
#include <rom/ets_sys.h>
#include <driver/gpio.h>
#include <soc/gpio_struct.h>

#define TAG "mdb_bill"

#define PIN_MDB_RX      GPIO_NUM_4
#define PIN_MDB_TX      GPIO_NUM_5
#define PIN_BOOT_BTN    GPIO_NUM_0   // BOOT button -> simulate $1 bill (type 0)

//---------------- MDB protocol --------------------//
#define BIT_MODE_SET    0b100000000
#define BIT_ADD_SET     0b011111000
#define BIT_CMD_SET     0b000000111

#define ACK             0x00    // Acknowledgment / checksum correct
#define RET             0xAA    // Retransmit previously sent data (VMC only)
#define NAK             0xFF    // Negative acknowledge

#define VALIDATOR_ADDR  0x30

enum VALIDATOR_CMD {
    VAL_RESET       = 0x00,
    VAL_SETUP       = 0x01,
    VAL_SECURITY    = 0x02,
    VAL_POLL        = 0x03,
    VAL_BILL_TYPE   = 0x04,
    VAL_ESCROW      = 0x05,
    VAL_STACKER     = 0x06,
    VAL_EXPANSION   = 0x07,
};

// POLL status codes (bit7 = 0)
enum VALIDATOR_STATUS {
    ST_DEFECTIVE_MOTOR   = 0x01,
    ST_SENSOR_PROBLEM    = 0x02,
    ST_VALIDATOR_BUSY    = 0x03,
    ST_ROM_CHECKSUM      = 0x04,
    ST_VALIDATOR_JAMMED  = 0x05,
    ST_VALIDATOR_RESET   = 0x06,   // Just Reset
    ST_BILL_REMOVED      = 0x07,
    ST_CASHBOX_OOP       = 0x08,
    ST_VALIDATOR_DISABLE = 0x09,
    ST_INVALID_ESCROW    = 0x0A,
    ST_BILL_REJECTED     = 0x0B,
    ST_CREDITED_REMOVAL  = 0x0C,
};

// Bill routing (bit7 = 1, bits 6-4 = route, bits 3-0 = type)
#define ROUTE_STACKED   (0 << 4)   // 0x80 | type
#define ROUTE_ESCROW    (1 << 4)   // 0x90 | type
#define ROUTE_RETURNED  (2 << 4)   // 0xA0 | type

typedef enum {
    INACTIVE_STATE,
    DISABLED_STATE,
    ENABLED_STATE,
} validator_state_t;

//---------------- Configuration -------------------//
// Currency 0xFFFF, scale factor 100, 2 decimals => credit 1 == $1.00.
#define MDB_CURRENCY_CODE   0xFFFF
#define MDB_SCALE_FACTOR    0x0064
#define MDB_DECIMAL_PLACES  0x02
#define STACKER_CAPACITY    500

// Bill credit in scaling-factor units. credit * scale_factor == cents/100.
static const uint8_t bill_credit[16] = {1, 2, 5, 10, 20, 50, 100, 0, 0, 0, 0, 0, 0, 0, 0, 0};

//---------------- Runtime state -------------------//
static validator_state_t validator_state = INACTIVE_STATE;
static bool     reset_validator_todo = false;
static uint16_t bill_enable    = 0x0000;   // set by BILL TYPE command
static uint16_t bill_escrow_en = 0x0000;   // set by BILL TYPE command
static uint16_t stacker_count  = 0;

// $1 bills queued by the BOOT button ISR, drained on the next POLL.
static volatile uint32_t pending_bills = 0;

static QueueHandle_t mdb_rx_queue;

//---------------- POLL event ring buffer ----------//
// Touched only by the MDB task, so no locking is required.
#define POLL_QSIZE 16
static uint8_t poll_q[POLL_QSIZE];
static uint8_t poll_q_head = 0;
static uint8_t poll_q_tail = 0;

static void poll_q_push(uint8_t b) {
    uint8_t next = (poll_q_head + 1) % POLL_QSIZE;
    if (next != poll_q_tail) {
        poll_q[poll_q_head] = b;
        poll_q_head = next;
    } else {
        ESP_LOGW(TAG, "poll queue full, event dropped");
    }
}

static bool poll_q_empty(void) { return poll_q_head == poll_q_tail; }

static uint8_t poll_q_pop(void) {
    uint8_t b = poll_q[poll_q_tail];
    poll_q_tail = (poll_q_tail + 1) % POLL_QSIZE;
    return b;
}

//---------------- Bill simulation -----------------//
static void simulate_bill(uint8_t bill_type) {
    if (bill_type > 15) return;

    if (validator_state != ENABLED_STATE) {
        ESP_LOGW(TAG, "bill ignored: validator not enabled");
        return;
    }
    if (!(bill_enable & (1 << bill_type))) {
        ESP_LOGW(TAG, "bill ignored: type=%d not enabled", bill_type);
        return;
    }

    // No escrow: bill is always accepted and stacked immediately.
    if (stacker_count < STACKER_CAPACITY) stacker_count++;
    poll_q_push(0x80 | ROUTE_STACKED | bill_type);
    ESP_LOGI(TAG, "bill stacked: type=%d credit=%d poll=0x%02X",
             bill_type, bill_credit[bill_type], 0x80 | ROUTE_STACKED | bill_type);
}

//---------------- 9-bit bit-bang I/O --------------//
static void IRAM_ATTR mdb_rx_falling_isr(void *arg) {
    gpio_intr_disable(PIN_MDB_RX);

    uint16_t coming_read = 0x0000;

    ets_delay_us(156);   // skip start bit, sample mid first data bit

    for (int x = 0; x < 9; x++) {
        coming_read |= (gpio_get_level(PIN_MDB_RX) << x);
        ets_delay_us(104);
    }
    xQueueSendFromISR(mdb_rx_queue, &coming_read, NULL);

    gpio_intr_enable(PIN_MDB_RX);
}

static uint16_t read_9(uint8_t *checksum) {
    uint16_t coming_read = 0;
    xQueueReceive(mdb_rx_queue, &coming_read, portMAX_DELAY);

    if (checksum)
        *checksum += coming_read;

    return coming_read;
}

static void write_9(uint16_t nth9) {
    gpio_set_level(PIN_MDB_TX, 0);   // start bit
    ets_delay_us(104);

    for (uint8_t x = 0; x < 9; x++) {
        gpio_set_level(PIN_MDB_TX, (nth9 >> x) & 1);
        ets_delay_us(104);
    }

    gpio_set_level(PIN_MDB_TX, 1);   // stop bit
    ets_delay_us(104);
}

static void write_payload_9(uint8_t *payload, uint8_t length) {
    uint8_t checksum = 0x00;

    // Half-duplex: don't listen while we talk. TX (GPIO5) couples into the adjacent
    // RX pin (GPIO4); the edge gets latched while RX is disabled and, on re-enable,
    // fires a spurious ISR that desyncs reception - so the next command from the VMC
    // right after this reply was dropped. Settle, drop garbage, clear edge, re-arm.
    gpio_intr_disable(PIN_MDB_RX);

    for (uint8_t x = 0; x < length; x++) {
        checksum += payload[x];
        write_9(payload[x]);
    }

    write_9(BIT_MODE_SET | checksum);   // checksum carries the MODE bit

    ets_delay_us(200);
    xQueueReset(mdb_rx_queue);
    GPIO.status_w1tc = (1U << PIN_MDB_RX);   // clear latched RX edge (GPIO4 < 32)
    gpio_intr_enable(PIN_MDB_RX);
}

//---------------- BOOT button ---------------------//
static void IRAM_ATTR boot_btn_isr(void *arg) {
    static int64_t last_us = 0;
    int64_t now = esp_timer_get_time();

    if (now - last_us < 200000) return;   // 200 ms debounce
    last_us = now;

    pending_bills++;
}

//---------------- MDB validator task --------------//
static void mdb_validator_task(void *pvParameters) {
    uint8_t mdb_payload[36];

    for (;;) {
        uint8_t checksum = 0x00;
        uint8_t available_tx = 0;

        uint16_t coming_read = read_9(&checksum);

        if (!(coming_read & BIT_MODE_SET)) continue;

        if ((uint8_t) coming_read == ACK) continue;
        if ((uint8_t) coming_read == RET) continue;
        if ((uint8_t) coming_read == NAK) continue;

        if ((coming_read & BIT_ADD_SET) != VALIDATOR_ADDR) continue;

        switch (coming_read & BIT_CMD_SET) {

        case VAL_RESET: {
            if (read_9(NULL) != checksum) continue;

            reset_validator_todo = true;
            validator_state = INACTIVE_STATE;
            bill_enable = 0x0000;
            bill_escrow_en = 0x0000;

            ESP_LOGI(TAG, "RESET");
            break;   // ACK (empty payload -> checksum only)
        }

        case VAL_SETUP: {
            if (read_9(NULL) != checksum) continue;

            validator_state = DISABLED_STATE;

            mdb_payload[0]  = 0x01;                          // Feature Level
            mdb_payload[1]  = MDB_CURRENCY_CODE >> 8;        // Currency Code High
            mdb_payload[2]  = MDB_CURRENCY_CODE & 0xFF;      // Currency Code Low
            mdb_payload[3]  = MDB_SCALE_FACTOR >> 8;         // Scaling Factor High
            mdb_payload[4]  = MDB_SCALE_FACTOR & 0xFF;       // Scaling Factor Low
            mdb_payload[5]  = MDB_DECIMAL_PLACES;            // Decimal Places
            mdb_payload[6]  = (STACKER_CAPACITY >> 8) & 0xFF;// Stacker Capacity High
            mdb_payload[7]  = STACKER_CAPACITY & 0xFF;       // Stacker Capacity Low
            mdb_payload[8]  = 0x00;                          // Security Levels High
            mdb_payload[9]  = 0x00;                          // Security Levels Low
            mdb_payload[10] = 0x00;                          // Escrow (0 = no escrow)
            for (int i = 0; i < 16; i++) mdb_payload[11 + i] = bill_credit[i];
            available_tx = 27;

            ESP_LOGI(TAG, "SETUP -> DISABLED");
            break;
        }

        case VAL_SECURITY: {
            (void) read_9(&checksum);   // security level high
            (void) read_9(&checksum);   // security level low
            if (read_9(NULL) != checksum) continue;

            ESP_LOGI(TAG, "SECURITY");
            break;   // ACK
        }

        case VAL_POLL: {
            if (read_9(NULL) != checksum) continue;

            // Inject queued BOOT-button $1 bills (type 0).
            while (pending_bills) {
                pending_bills--;
                simulate_bill(0);
            }

            if (reset_validator_todo) {
                reset_validator_todo = false;
                validator_state = DISABLED_STATE;
                mdb_payload[0] = ST_VALIDATOR_RESET;   // Just Reset
                available_tx = 1;
                ESP_LOGI(TAG, "POLL -> Just Reset");
            } else {
                while (!poll_q_empty() && available_tx < 16) {
                    uint8_t b = poll_q_pop();
                    mdb_payload[available_tx++] = b;
                    if (b & 0x80)
                        ESP_LOGI(TAG, "POLL -> bill event 0x%02X (route=%d type=%d)",
                                 b, (b >> 4) & 0x07, b & 0x0F);
                    else
                        ESP_LOGI(TAG, "POLL -> status 0x%02X", b);
                }
            }
            break;
        }

        case VAL_BILL_TYPE: {
            uint8_t en_high  = (uint8_t) read_9(&checksum);   // bill enable high
            uint8_t en_low   = (uint8_t) read_9(&checksum);   // bill enable low
            uint8_t esc_high = (uint8_t) read_9(&checksum);   // bill escrow enable high
            uint8_t esc_low  = (uint8_t) read_9(&checksum);   // bill escrow enable low
            if (read_9(NULL) != checksum) continue;

            bill_enable    = ((uint16_t) en_high  << 8) | en_low;
            bill_escrow_en = ((uint16_t) esc_high << 8) | esc_low;

            validator_state = bill_enable ? ENABLED_STATE : DISABLED_STATE;

            ESP_LOGI(TAG, "BILL_TYPE enable=0x%04X escrow=0x%04X -> %s",
                     bill_enable, bill_escrow_en,
                     validator_state == ENABLED_STATE ? "ENABLED" : "DISABLED");
            break;   // ACK
        }

        case VAL_ESCROW: {
            // No escrow capability: bills already stacked at insertion. Just ACK.
            (void) read_9(&checksum);   // escrow byte (bit0: 1=stack, 0=return)
            if (read_9(NULL) != checksum) continue;

            ESP_LOGI(TAG, "ESCROW (no-op, escrow disabled)");
            break;   // ACK
        }

        case VAL_STACKER: {
            if (read_9(NULL) != checksum) continue;

            uint16_t full = (stacker_count >= STACKER_CAPACITY) ? 0x8000 : 0x0000;
            uint16_t val  = full | (stacker_count & 0x7FFF);
            mdb_payload[0] = (val >> 8) & 0xFF;   // bit15 = full flag
            mdb_payload[1] = val & 0xFF;
            available_tx = 2;

            ESP_LOGI(TAG, "STACKER count=%d full=%d", stacker_count, full ? 1 : 0);
            break;
        }

        case VAL_EXPANSION: {
            uint8_t sub = (uint8_t) read_9(&checksum);

            if (sub == 0x00) {   // REQUEST_ID / Identification
                if (read_9(NULL) != checksum) continue;

                memcpy(&mdb_payload[0],  "MDB", 3);   // Manufacturer Code
                memset(&mdb_payload[3],  ' ', 12);    // Serial Number
                memset(&mdb_payload[15], ' ', 12);    // Model / Tuning Revision
                mdb_payload[27] = 0x00;               // Software Version High
                mdb_payload[28] = 0x01;               // Software Version Low
                available_tx = 29;

                ESP_LOGI(TAG, "EXPANSION REQUEST_ID");
            }
            break;
        }

        }

        write_payload_9(mdb_payload, available_tx);
    }
}

//---------------- Entry point ---------------------//
void app_main(void) {
    // MDB RX: input, falling-edge interrupt.
    gpio_config_t rx_cfg = {
        .pin_bit_mask = 1ULL << PIN_MDB_RX,
        .mode         = GPIO_MODE_INPUT,
        .pull_up_en   = GPIO_PULLUP_ENABLE,
        .intr_type    = GPIO_INTR_NEGEDGE,
    };
    gpio_config(&rx_cfg);

    // MDB TX: output, idle high.
    gpio_config_t tx_cfg = {
        .pin_bit_mask = 1ULL << PIN_MDB_TX,
        .mode         = GPIO_MODE_OUTPUT,
    };
    gpio_config(&tx_cfg);
    gpio_set_level(PIN_MDB_TX, 1);

    // BOOT button: input, pull-up, falling-edge interrupt.
    gpio_config_t btn_cfg = {
        .pin_bit_mask = 1ULL << PIN_BOOT_BTN,
        .mode         = GPIO_MODE_INPUT,
        .pull_up_en   = GPIO_PULLUP_ENABLE,
        .intr_type    = GPIO_INTR_NEGEDGE,
    };
    gpio_config(&btn_cfg);

    mdb_rx_queue = xQueueCreate(64, sizeof(uint16_t));

    gpio_install_isr_service(0);
    gpio_isr_handler_add(PIN_MDB_RX, mdb_rx_falling_isr, NULL);
    gpio_isr_handler_add(PIN_BOOT_BTN, boot_btn_isr, NULL);

    ESP_LOGI(TAG, "init RX=%d TX=%d addr=0x%02X (BOOT btn -> $1 bill)",
             PIN_MDB_RX, PIN_MDB_TX, VALIDATOR_ADDR);

    xTaskCreate(mdb_validator_task, "mdb_validator", 4096, NULL, 10, NULL);
}

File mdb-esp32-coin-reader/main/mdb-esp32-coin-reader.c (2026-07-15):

/*
 * VMflow.xyz
 *
 * mdb-esp32-coin-reader.c - MDB Coin Changer peripheral (ESP32-S3)
 *
 * Emulates an MDB Level 3 coin changer (address 0x08). The BOOT button
 * on GPIO0 injects a 25c coin (type 2) event for bench testing.
 *
 * MDB lines are bit-banged at 9600 baud, 9 data bits (the 9th bit is the
 * MODE bit). RX is sampled inside a falling-edge ISR; TX is shifted out by
 * busy-wait. Same low-level scheme as the cashless peripheral.
 */

#include <stdio.h>
#include <string.h>
#include <freertos/FreeRTOS.h>
#include <freertos/task.h>
#include <freertos/queue.h>
#include <esp_log.h>
#include <esp_timer.h>
#include <rom/ets_sys.h>
#include <driver/gpio.h>
#include <soc/gpio_struct.h>

#define TAG "mdb_changer"

#define PIN_MDB_RX      GPIO_NUM_4
#define PIN_MDB_TX      GPIO_NUM_5
#define PIN_BOOT_BTN    GPIO_NUM_0   // BOOT button -> simulate 25c coin (type 2)

//---------------- MDB protocol --------------------//
#define BIT_MODE_SET    0b100000000
#define BIT_ADD_SET     0b011111000
#define BIT_CMD_SET     0b000000111

#define ACK             0x00    // Acknowledgment / checksum correct
#define RET             0xAA    // Retransmit previously sent data (VMC only)
#define NAK             0xFF    // Negative acknowledge

#define CHANGER_ADDR    0x08

enum CHANGER_CMD {
    CHANGER_RESET       = 0x00,
    CHANGER_SETUP       = 0x01,
    CHANGER_TUBE_STATUS = 0x02,
    CHANGER_POLL        = 0x03,
    CHANGER_COIN_TYPE   = 0x04,
    CHANGER_DISPENSE    = 0x05,
    CHANGER_EXPANSION   = 0x07,
};

// POLL status/error codes
enum CHANGER_STATUS {
    ST_ESCROW_REQUEST       = 0x01,
    ST_CHANGER_PAYOUT_BUSY  = 0x02,
    ST_NO_CREDIT            = 0x03,
    ST_DEFECTIVE_SENSOR     = 0x04,
    ST_DOUBLE_ARRIVAL       = 0x05,
    ST_ACCEPTOR_UNPLUGGED   = 0x06,
    ST_TUBE_JAM             = 0x07,
    ST_ROM_CHECKSUM         = 0x08,
    ST_COIN_ROUTING_ERR     = 0x09,
    ST_CHANGER_BUSY         = 0x0A,
    ST_CHANGER_RESET        = 0x0B,  // Changer was reset
    ST_COIN_JAM             = 0x0C,
};

typedef enum {
    INACTIVE_STATE,
    DISABLED_STATE,
    ENABLED_STATE,
} changer_state_t;

//---------------- Configuration -------------------//
// Scaling factor 1, 2 decimal places => credit 5 == $0.05.
#define MDB_CURRENCY_CODE   0xFFFF
#define MDB_SCALE_FACTOR    0x01
#define MDB_DECIMAL_PLACES  0x02
#define TUBE_CAPACITY       100

// Coin values (credit * scale_factor)
static const uint8_t coin_credit[16] = {5, 10, 25, 100, 0, 0, 0, 0, 0, 0, 0, 0, 0, 0, 0, 0};

//---------------- Runtime state -------------------//
static changer_state_t changer_state = INACTIVE_STATE;
static bool     reset_changer_todo = false;
static uint16_t coin_enable    = 0x0000;   // set by COIN TYPE command
static uint16_t dispense_enable = 0x0000;  // set by COIN TYPE command
static uint8_t  tube_count[16]  = {0};

static volatile uint32_t pending_coins = 0;
static QueueHandle_t mdb_rx_queue;

//---------------- POLL event ring buffer ----------//
// Touched only by the MDB task, so no locking is required.
#define POLL_QSIZE 32
static uint8_t poll_q[POLL_QSIZE];
static uint8_t poll_q_head = 0;
static uint8_t poll_q_tail = 0;

static void poll_q_push(uint8_t b) {
    uint8_t next = (poll_q_head + 1) % POLL_QSIZE;
    if (next != poll_q_tail) {
        poll_q[poll_q_head] = b;
        poll_q_head = next;
    } else {
        ESP_LOGW(TAG, "poll queue full, event dropped");
    }
}

static bool poll_q_empty(void) { return poll_q_head == poll_q_tail; }

static uint8_t poll_q_pop(void) {
    uint8_t b = poll_q[poll_q_tail];
    poll_q_tail = (poll_q_tail + 1) % POLL_QSIZE;
    return b;
}

//---------------- Coin simulation -----------------//
static void simulate_coin(uint8_t coin_type) {
    if (coin_type > 15) return;

    if (changer_state != ENABLED_STATE) {
        ESP_LOGW(TAG, "coin ignored: changer not enabled");
        return;
    }
    if (!(coin_enable & (1 << coin_type))) {
        ESP_LOGW(TAG, "coin ignored: type=%d not enabled", coin_type);
        return;
    }

    // Determine routing: route to tube if space exists, otherwise to cash box
    uint8_t routing = 0; // 0 = cash box, 1 = tubes
    if (tube_count[coin_type] < TUBE_CAPACITY) {
        tube_count[coin_type]++;
        routing = 1; // tubes
    } else {
        routing = 0; // cash box
    }

    // Push 2-byte event to poll queue:
    // Byte 1: 0x40 | (routing << 4) | coin_type
    // Byte 2: tube_count[coin_type]
    poll_q_push(0x40 | (routing << 4) | coin_type);
    poll_q_push(tube_count[coin_type]);

    ESP_LOGI(TAG, "coin deposited: type=%d credit=%d routing=%s tube_count=%d",
             coin_type, coin_credit[coin_type],
             routing == 1 ? "TUBES" : "CASHBOX",
             tube_count[coin_type]);
}

//---------------- 9-bit bit-bang I/O --------------//
static void IRAM_ATTR mdb_rx_falling_isr(void *arg) {
    gpio_intr_disable(PIN_MDB_RX);

    uint16_t coming_read = 0x0000;

    ets_delay_us(156);   // skip start bit, sample mid first data bit

    for (int x = 0; x < 9; x++) {
        coming_read |= (gpio_get_level(PIN_MDB_RX) << x);
        ets_delay_us(104);
    }
    xQueueSendFromISR(mdb_rx_queue, &coming_read, NULL);

    gpio_intr_enable(PIN_MDB_RX);
}

static uint16_t read_9(uint8_t *checksum) {
    uint16_t coming_read = 0;
    xQueueReceive(mdb_rx_queue, &coming_read, portMAX_DELAY);

    if (checksum)
        *checksum += coming_read;

    return coming_read;
}

static void write_9(uint16_t nth9) {
    gpio_set_level(PIN_MDB_TX, 0);   // start bit
    ets_delay_us(104);

    for (uint8_t x = 0; x < 9; x++) {
        gpio_set_level(PIN_MDB_TX, (nth9 >> x) & 1);
        ets_delay_us(104);
    }

    gpio_set_level(PIN_MDB_TX, 1);   // stop bit
    ets_delay_us(104);
}

static void write_payload_9(uint8_t *payload, uint8_t length) {
    uint8_t checksum = 0x00;

    // Half-duplex: don't listen while we talk. The RX falling-edge ISR would
    // otherwise trigger on our own transmission (TX/RX are coupled on the shared
    // point-to-point bus) and queue spurious bytes, desyncing the framing so the
    // very next command from the VMC (the POLL right after this ACK) was lost.
    gpio_intr_disable(PIN_MDB_RX);

    for (uint8_t x = 0; x < length; x++) {
        checksum += payload[x];
        write_9(payload[x]);
    }

    write_9(BIT_MODE_SET | checksum);   // checksum carries the MODE bit

    // TX (GPIO5) capacitively couples into the adjacent RX pin (GPIO4). The
    // resulting edge gets LATCHED in the interrupt status while RX is disabled
    // and, on re-enable, fires a spurious ISR that desyncs reception - so the
    // coin dropped exactly one command after every reply. Let it settle, drop
    // any queued garbage, clear the latched edge, then re-arm clean.
    esp_rom_delay_us(200);
    xQueueReset(mdb_rx_queue);
    GPIO.status_w1tc = (1U << PIN_MDB_RX);   // clear latched RX edge (GPIO4 < 32)
    gpio_intr_enable(PIN_MDB_RX);
}
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

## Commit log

2026-05-30 Initial commit: MDB ESP32 vending machine controller
    VMC (MDB master) firmware for ESP32: polls coin changer, bill
    validator, and cashless reader, with EVA-DTS DEX and a KiCad
    bare-metal board (dual MDB controller/target ports).
    [Connector_Molex-MiniJr-39-28-1063_2x03.stp, Inductor_WE-7447789156_100uH.stp, LED_WS2812B-2020_XL-2121RGBC.stp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]
2026-06-07 fix(mdb): widen POLL window to 60ms and poll-fail threshold to 10
    Bench-validated against the mdb-bill-reader emulator on a live MDB bus:
    - ENABLED-state POLL read for changer (0x08) and validator (0x30) used a 30ms
    window. A real peripheral can spread its multi-byte deposit/bill event reply
    past 30ms, truncating the read so the coin/bill event was lost. Widen to 60ms
    (costs ~30ms more per idle poll, which already blocks the full window).
    - poll_fail_count threshold of 3 dropped a device to INACTIVE on a brief bus
    glitch (one slow loop / corrupted POLL), forcing a full re-handshake. Raise to
    10 so transient disruption is tolerated; a genuinely absent device still drops
    in well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
    [mdb-master-esp32s3.c]
2026-06-15 tlp7185^Co tlp785
    [mdb-vmc-esp32s3.kicad_sch]
2026-06-19 Add MDB PCB connection diagram to README
    Added a diagram of the MDB PCB connection to the README.
2026-06-19 Remove duplicate MDB PCB connection diagram
    Removed duplicate MDB PCB connection diagram from README.
2026-06-24 Add MDB bill validator peripheral (ESP32-S3)
    Emulates an MDB Level 1 bill validator (address 0x30) using the
    bit-banged 9-bit UART scheme. Implements RESET/SETUP/SECURITY/POLL/
    BILL_TYPE/ESCROW/STACKER/EXPANSION per MDB 4.2 section 6. BOOT button
    on GPIO0 injects a $1 bill (type 0) for bench testing.
    [mdb-esp32-bill-reader.c]
2026-07-02 Add MDB controller<->target bridge with cashless arbitration, BLE/WiFi/MQTT/OTA and safe RPC
    Rewrites main/mdb-master-esp32s3.c from a standalone VMC into a dual-port
    bridge: the controller port (UART2, master) drives physical coin changer,
    bill validator, and an optional external cashless; the target port
    (bit-banged, slave) emulates all three toward the vending machine's real
    VMC. Coin/bill are bridged as repeaters mirroring the real device's
    scale/decimal/tube/stacker state; cashless is arbitrated between an
    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
2026-07-02 Add mdb-esp32-coin-reader standalone MDB changer peripheral project
    Adds the ESP-IDF project scaffold (CMakeLists.txt, .gitignore, sdkconfig)
    for the MDB Level 3 coin changer peripheral (address 0x08) whose source
    was already present, so it builds standalone. Unrelated to the
    controller<->target bridge in this branch.
2026-07-15 Refactor main to coin/bill/cashless bridge, remove BLE/WiFi/MQTT/OTA/RPC
    - Rewrote mdb-master-esp32s3.c: pure 3-device bridge (coin 0x08, bill 0x30,
    cashless 0x10) with controller task on core 0 and target task on core 1
    - Controller port: plug-and-play per-device FSM (INACTIVE→DISABLED→ENABLED)
    - Target port: always-online emulation with zero/default initial state
    - Added cashless bridge with bidirectional queues (cashless_to_target_queue /
    cashless_from_target_queue) exposed non-static for future BLE/MQTT engines
    - Cashless target FSM: RESET/SETUP/POLL/VEND/READER/EXPANSION + 60s session timeout
    - Fixed coin reader initial tube_count zeroed to avoid "Collect Change" on VMC
    - Fixed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
    [mdb-esp32-bill-reader.c, mdb-esp32-coin-reader.c, mdb-master-esp32s3.c]
2026-07-15 Harden cashless vend flow and fix peripheral currency reporting
    Re-integrate BLE/WiFi/MQTT/OTA/RPC into the controller<->target bridge
    (new nimble.c/h and rpc-auth.c/h), and stabilize the payment path:
    - Begin Session only when the reader is ENABLED, so credit is no longer
    consumed and sent out-of-sequence (dropped payments).
    - Decide vend locally for any funded (non-0xFFFF) session, including a
    zero balance, instead of hanging when funds == 0.
    - Deduct the vended price on Vend Success so multi-vend sessions keep an
    accurate balance.
    - Only ever raise the BLE approve/cancel flags, never clear them, to avoid
    losing a decision to a cross-task write.
    - Report the real peripheral countr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
    [mdb-master-esp32s3.c]
2026-07-17 fix(esp32): bump IDF to 5.1, fix BLE buffer handling
    - Upgrade IDF requirement from 4.1.0 to 5.1
    - BLE: memset buffer before write, adjust size parameter to avoid overflow
2026-08-16 chore: consolidate and expand .gitignore
    Remove redundant sub-project gitignores (root build/ already covers
    them). Add KiCad temp files and editor/OS patterns.
2026-08-16 chore(kicad): reorganize into per-project subdirectories
    Move mdb-vmc-esp32s3 files into own subdir. Add mdb-ai-bridge-esp32s3
    project.
    [Connector_Molex-MiniJr-39-28-1063_2x03.stp, Inductor_WE-7447789156_100uH.stp, LED_WS2812B-2020_XL-2121RGBC.stp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]
2026-08-16 chore: ignore *.kicad_prl and untrack existing one
    Local KiCad project settings should not be versioned.
2026-08-16 refactor(kicad): rename mdb-vmc-esp32s3 to mdb-bridge-esp32s3
    Update directory, filenames, and internal .kicad_pro reference.
    [Connector_Molex-MiniJr-39-28-1063_2x03.stp, Inductor_WE-7447789156_100uH.stp, LED_WS2812B-2020_XL-2121RGBC.stp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]
2026-08-16 feat(kicad): update mdb-ai-bridge-esp32s3 schematic
    [mdb-ai-bridge-esp32s3.kicad_sch]
2026-08-16 feat(kicad): fill missing LCSC# for 9 components in mdb-ai-bridge
    [mdb-ai-bridge-esp32s3.kicad_sch]
2026-08-16 feat(kicad): add LCSC# field to remaining 4 components
    U13 (AMS1117-3.3) -> C6186, U14 (USB2514B_Bi) -> C510949.
    AE3 and H2 get empty field (PCB antenna / mechanical hole).
    [mdb-ai-bridge-esp32s3.kicad_sch]
2026-08-16 feat(kicad): add PCB layout and update schematic for mdb-ai-bridge-esp32s3
    PCB was previously a placeholder (empty board). Full routing and component
    placement now added. Schematic also updated with matching changes.
    [mdb-ai-bridge-esp32s3.kicad_pcb, mdb-ai-bridge-esp32s3.kicad_sch]
2026-08-19 fix: add LCSC# C15500 to C22 (22uF 0603)
    [mdb-bridge-esp32s3.kicad_sch]
2026-08-25 fix(hardware): standardize Value field notation in schematics
    4K7→4.7k, 470ohm→470R, 1.8pf→1.8pF, 2.4nh→2.4nH,
    Crystal_GND24→40MHz/24MHz (por LCSC), FerriteBead_Small→FerriteBead
    [mdb-ai-bridge-esp32s3.kicad_sch, mdb-bridge-esp32s3.kicad_sch]
2026-08-30 fix(hardware): update LCSC# and values in mdb-bridge-esp32s3 schematic
    - C3: Value "?" → "1uF", LCSC# → C696901 (AP2112K-3.3 input cap)
    - C1, C2, C15: LCSC# C6119849 → C696901 (discontinued → active 1uF 16V X5R 0603)
    - C32: Value "220uF" → "100uF", LCSC# → C90975 (LM2594HVM-5V output, 10V CASE-B derating)
    Claude-Session: https://claude.ai/code/session_01Qh1XTvg8Um6L2D2gYWdT7R
    [mdb-ai-bridge-esp32s3.kicad_pcb, mdb-bridge-esp32s3.kicad_pcb, mdb-bridge-esp32s3.kicad_sch]
2026-08-30 Refine .gitignore for ESP-IDF and KiCad artifacts
    Explicitly ignore sdkconfig.old and *.kicad_sch.bak, and consolidate
    the ESP-IDF build/managed_components block.
2026-09-01 Reorganize PCB layout: declutter, grid-align, rotate R/C, fix labels
    - Declutter overlapping/off-board footprints via courtyard-based AABB
    relaxation (241 collisions -> 0, 94 footprints).
    - Snap R/C to 0.5mm grid with local collision repair.
    - Reflow layout to fit shrunk Edge.Cuts outline.
    - Row-align R/C sharing an electrical cluster (17 footprints).
    - Rotate 20 R/C 180 deg toward nearest same-net pad for shorter routes.
    - Shrink R/C reference labels 1.0mm -> 0.5mm and reposition 50 that
    still collided, per user's chosen option.
    Final: 0 courtyard collisions board-wide (only mounting hole H2
    intentionally off strict edge margin).
    [mdb-ai-bridge-esp32s3.kicad_pcb]
2026-09-01 Enlarge Edge.Cuts to 64x41mm and move H2 mounting hole to right edge
    - Edge.Cuts was 58x37mm, too small for the 94 placed footprints
    (needed ~59.2x37.7mm); grew outline to (130,75)-(194,116) instead of
    compacting placement.
    - H2 mounting hole moved to x=194 (board right edge) so its courtyard
    sits exactly 50% inside / 50% outside the board, per request.
    - Validated with pcbnew (python): 0 footprints outside Edge.Cuts
    (except H2, intentionally straddling) and kicad-cli drc (176
    pre-existing violations unchanged, no new ones from this change).
    Claude-Session: https://claude.ai/code/session_0141XSaXvjY2LuYvwcHP9FdA
    [mdb-ai-bridge-esp32s3.kicad_pcb]

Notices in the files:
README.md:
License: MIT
